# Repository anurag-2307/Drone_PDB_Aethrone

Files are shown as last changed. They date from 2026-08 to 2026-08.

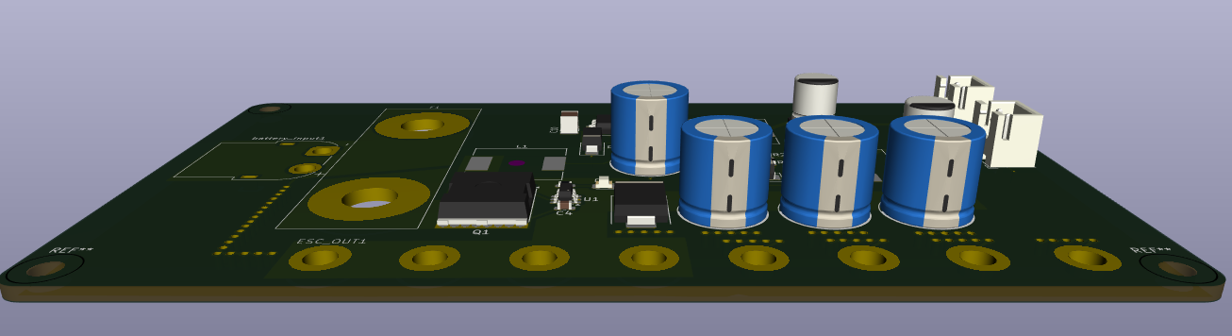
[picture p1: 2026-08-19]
images/3D_x_axis_view.png

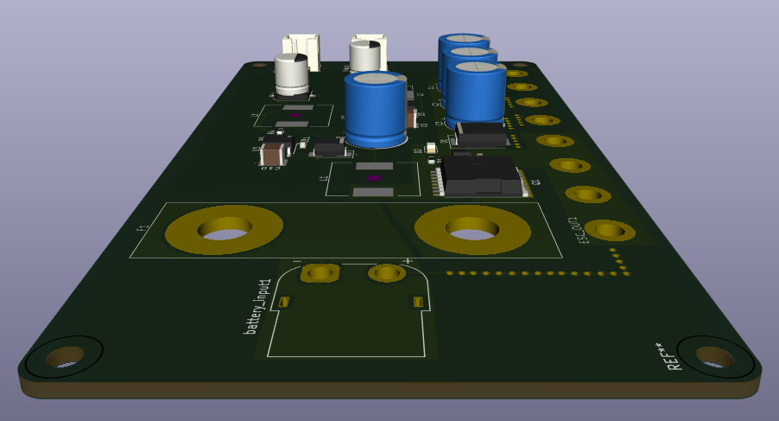
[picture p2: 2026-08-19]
images/3D_z_axis_view.png

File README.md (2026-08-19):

# Drone_PDB_Aethrone

---

Candidate : Anurag Patankar

Personal Email : patankaranurag23@gmail.com

---

### Problem Statement :
Drone Power Distribution Board (PDB)

---
### Objective : 
Design a Power Distribution Board (PDB) for a medium-sized multirotor UAV capable of safely distributing power from a 6S LiPo battery to the avionics and propulsion systems.

## System Specifications

Input source - 6S LiPo battery, 18 V – 25.2 V (3.0–4.2 V/cell)
Continuous current - 80 A
Peak current - 120 A
Regulated outputs -	5 V @ 3 A, 12 V @ 2 A
Unregulated output  -	Battery voltage direct to ESC1–ESC4
PCB	2-layer, 3 oz copper (both outer layers)
Target thermal design margin - 20 °C rise above ambient
Input Connectors - XT60 (6S LiPo datasheet suggests XT90 for 80A continuous current, but the problem statement mentioned this, so I have used XT60 instead)
Output Connectors (Non-ESC) - JST
Output Connectors (ESC) - Solder holes

Note: Copper sizing is assumed to be at 3oz as it was not mentioned which size is to be used in the problem statement.

---

### Input Protection

1. Reverse Polarity Protection — U1 (LM74700) + Q1 (IPT015N10N5)

Rather than a series diode (which would waste power as heat at 80 A) , meaning 24–40 W burned continuously), the board uses an ideal diode controller driving an N-channel MOSFET, which behaves like a near-lossless diode.

U1 – TI LM74700-Q1: an ideal-diode controller rated for a 3.2 V–65 V supply range, covering the 18–25.2 V input. It drives an external NMOS and regulates its forward voltage drop to ~20 mV, versus the 300–500 mV of a real diode. It also blocks reverse current if the battery is momentarily disconnected/reconnected backward or during a fault, and responds in under 1 µs.
Q1 – Infineon IPT015N10N5: a 100 V, 300 A-rated N-channel MOSFET with a maximum Rds(on) of 1.5 mΩ. At 80 A continuous, conduction loss is I²R = 80² × 0.0015 ≈ 9.6 W; at 120 A peak, ≈21.6 W. The 300 A / 100 V rating gives sufficient margin over the operating envelope of 80 A/25.2 V. This MOSFET choice is what makes a lossless reverse polarity protection stage feasible at this current level, since a lower-current MOSFET would need paralleling.

---
2. TVS Diode

A unidirectional TVS Diode is placed across the protected rail to protect against voltage spikes. When the MOSFET turns off, it will create high voltage spikes (V = L. di/dt). To suppress this,  we use a bulk capacitor(s). E = $\frac{1}{2} \cdot L \cdot I$ and since the energy needs to be stored in the capacitor as well, $E = \frac{1}{2} \cdot C \cdot (V_{max}^2 - V_{nominal}^2)$. After some calculations, we get about C = 1666uF. To minimize the ESR, we place these in parallel instead of 1 big capacitor. Hence 680u * 3 = 2040uF.  

---
3. Fuse

Since we have to handle 120A (peak), the fuse needs to be a MIDI/MEGA style fuse. Since KiCAD doesn't have these footprints readily available, I created it myself with through-holes so that it can be soldered later on.

---
4. TPS5430, TPS5420 buck converters

We needed 5V@3A and 12V@2A, thus these buck converters were chosen after going through the datasheet. TPS5430 can provide a constant current of about 3A, while the TPS5420 can provide a constant current of 2A. 

Feedback Resistors calculation (TPS5430):
Vout = Vref × (1 + R2/R3)
5 V = 1.221 V × (1 + 10 kΩ / R3)
R3 = 10 kΩ / (5/1.221 − 1) ≈ 3.24 kΩ

(TPS5420):
12 V = 1.221 V × (1 + 10 kΩ / R5)
R5 = 10 kΩ / (12/1.221 − 1) ≈ 1.13 kΩ

---
5. Trace Width Calculation:

120 A peak (peak) at 3 oz for	20 °C rise (assuming) is about ~7917 mil²	≈ 48.6 mm which is massive. That is why I have used copper pour instead to dissipate heat evenly.
3A constant at 5V => 1 mm width. This is deliberately kept higher to reduce IR drop, and it also keeps output regulation tighter under load. 
2A constant at 12V => 1 mm width. Same reasoning as above. 

The standard used to calculate the trace widths is **IPC-2221**.

---
6. Via sizing
Via sizing basis: 0.8 mm drill / 1.2 mm pad, ≈4.8 A per via at 20 °C rise (1 oz barrel plating assumed). Thus for each ESC output, TVS diode GND, Bulk capacitor GND, 5 vias are placed and about 20 for Battery input ground pin. Default via sizes are used for all other components.

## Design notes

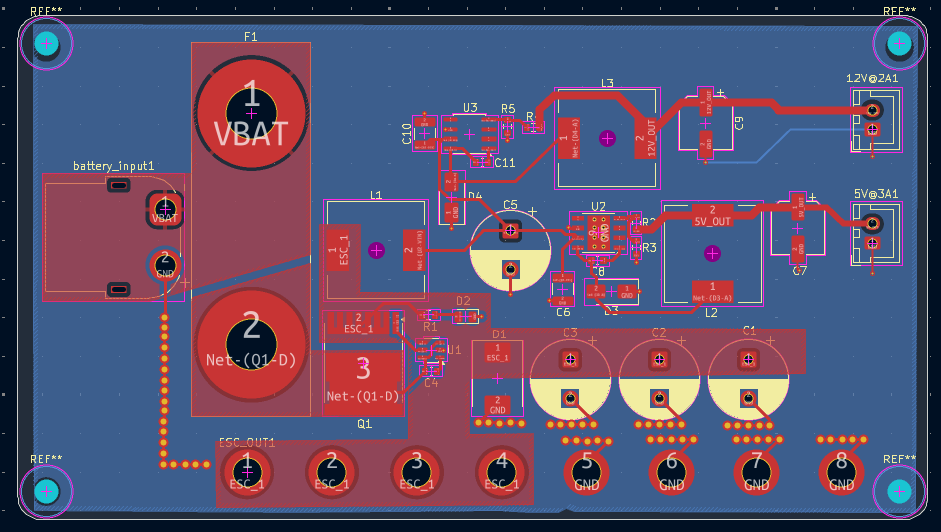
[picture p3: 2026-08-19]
images/Layout_view.png

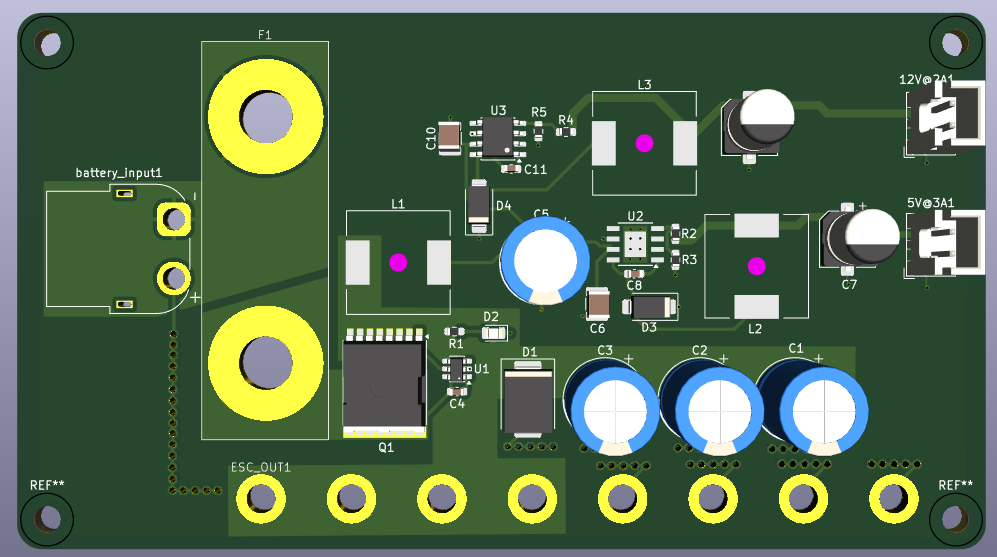
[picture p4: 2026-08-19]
images/3D_top_view.png

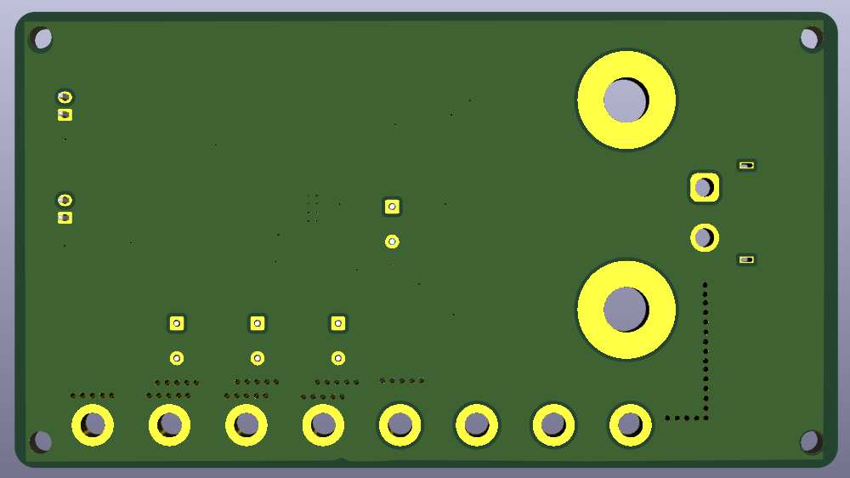
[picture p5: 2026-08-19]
images/3D_bottom_view.png

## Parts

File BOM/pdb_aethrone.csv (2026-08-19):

Reference | Qty | Value | DNP | Exclude from BOM | Exclude from Board | Exclude from Simulation | Exclude from Position Files | Footprint | Datasheet
5V@3A1,12V@2A1 | 2 | Conn_01x02_Pin |  |  |  |  | ${EXCLUDE_FROM_POS_FILES} | Connector_JST:JST_XH_B2B-XH-A_1x02_P2.50mm_Vertical
battery_input1 | 1 | Conn_01x02_Pin |  |  |  |  | ${EXCLUDE_FROM_POS_FILES} | Connector_AMASS:AMASS_XT60PW-F_1x02_P7.20mm_Horizontal
C1,C2,C3,C5 | 4 | 680u |  |  |  |  | ${EXCLUDE_FROM_POS_FILES} | Capacitor_THT:CP_Radial_D10.0mm_P5.00mm
C4 | 1 | 100n |  |  |  |  | ${EXCLUDE_FROM_POS_FILES} | Capacitor_SMD:C_0603_1608Metric
C6,C10 | 2 | 10u |  |  |  |  | ${EXCLUDE_FROM_POS_FILES} | Capacitor_SMD:C_1210_3225Metric
C7 | 1 | 220u |  |  |  |  | ${EXCLUDE_FROM_POS_FILES} | Capacitor_SMD:CP_Elec_6.3x7.7
C8,C11 | 2 | 10n |  |  |  |  | ${EXCLUDE_FROM_POS_FILES} | Capacitor_SMD:C_0603_1608Metric
C9 | 1 | 100u |  |  |  |  | ${EXCLUDE_FROM_POS_FILES} | Capacitor_SMD:CP_Elec_6.3x7.7
D1 | 1 | TVS_D |  |  |  |  | ${EXCLUDE_FROM_POS_FILES} | Diode_SMD:D_SMC
D2 | 1 | LED |  |  |  |  | ${EXCLUDE_FROM_POS_FILES} | LED_SMD:LED_0805_2012Metric
D3,D4 | 2 | B340 |  |  |  |  | ${EXCLUDE_FROM_POS_FILES} | Diode_SMD:D_SMA | http://www.jameco.com/Jameco/Products/ProdDS/1538777.pdf
ESC_OUT1 | 1 | Conn_01x08_Pin |  |  |  |  | ${EXCLUDE_FROM_POS_FILES} | Library_fuse:ESC_Pins
F1 | 1 | Fuse |  |  |  |  | ${EXCLUDE_FROM_POS_FILES} | Library_fuse:Untitled
L1 | 1 | 22u |  |  |  |  | ${EXCLUDE_FROM_POS_FILES} | Inductor_SMD:L_12x12mm_H6mm
L2 | 1 | 15u |  |  |  |  | ${EXCLUDE_FROM_POS_FILES} | Inductor_SMD:L_12x12mm_H6mm
L3 | 1 | 33u |  |  |  |  | ${EXCLUDE_FROM_POS_FILES} | Inductor_SMD:L_12x12mm_H6mm
Q1 | 1 | IPT015N10N5 |  |  |  |  | ${EXCLUDE_FROM_POS_FILES} | Package_TO_SOT_SMD:Infineon_PG-HSOF-8-1 | http://www.infineon.com/dgdl/Infineon-IPT015N10N5-DS-v02_01-EN.pdf?fileId=5546d4624a75e5f1014ac94680661aff
R1,R2,R4 | 3 | 10k |  |  |  |  | ${EXCLUDE_FROM_POS_FILES} | Resistor_SMD:R_0603_1608Metric
R3 | 1 | 3.24k |  |  |  |  | ${EXCLUDE_FROM_POS_FILES} | Resistor_SMD:R_0603_1608Metric
R5 | 1 | 1.13k |  |  |  |  | ${EXCLUDE_FROM_POS_FILES} | Resistor_SMD:R_0603_1608Metric
U1 | 1 | LM74700 |  |  |  |  | ${EXCLUDE_FROM_POS_FILES} | Package_TO_SOT_SMD:SOT-23-6 | http://www.ti.com/lit/gpn/LM74700-Q1
U2 | 1 | TPS5430DDA |  |  |  |  | ${EXCLUDE_FROM_POS_FILES} | Package_SO:TI_SO-PowerPAD-8_ThermalVias | http://www.ti.com/lit/ds/symlink/tps5430.pdf
U3 | 1 | TPS5420D |  |  |  |  | ${EXCLUDE_FROM_POS_FILES} | Package_SO:SOIC-8_3.9x4.9mm_P1.27mm | http://www.ti.com/lit/ds/symlink/tps5420.pdf

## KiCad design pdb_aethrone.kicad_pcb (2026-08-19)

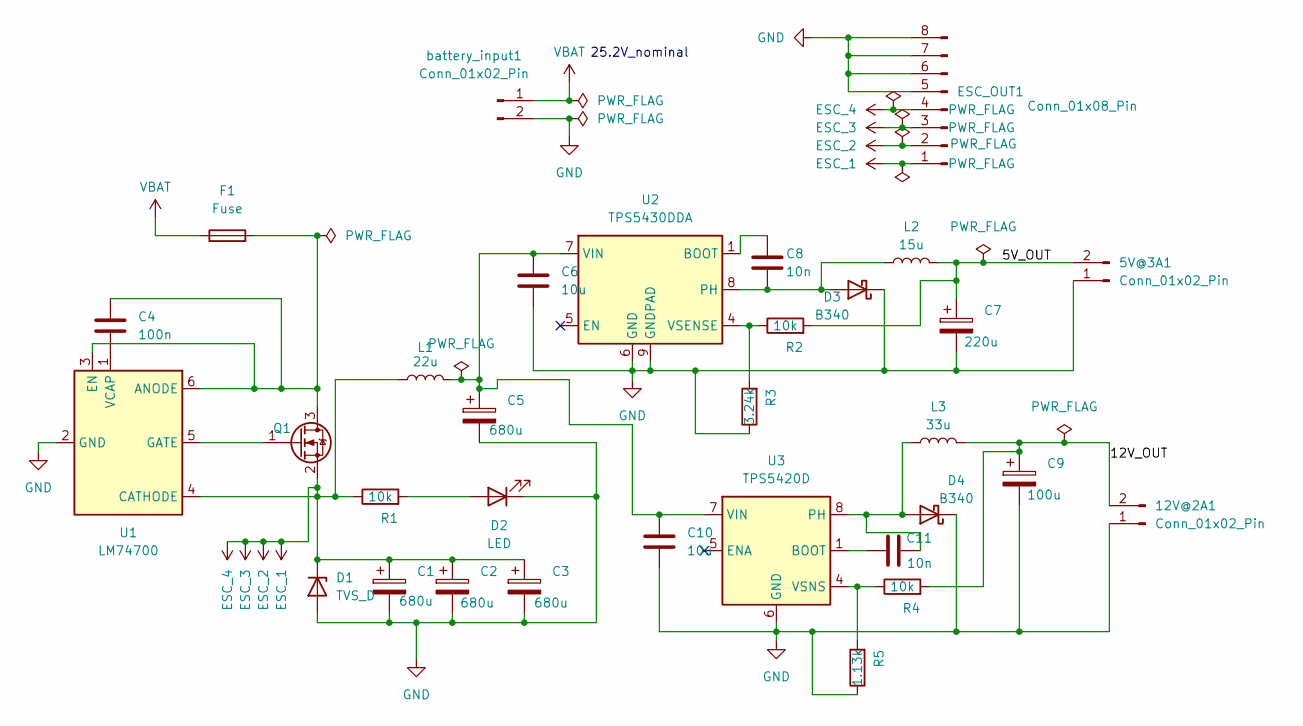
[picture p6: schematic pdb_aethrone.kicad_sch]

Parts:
5V@3A1, 12V@2A1: Conn_01x02_Pin; JST_XH_B2B-XH-A_1x02_P2.50mm_Vertical
C1, C2, C3, C5: 680u; CP_Radial_D10.0mm_P5.00mm
C4: 100n; C_0603_1608Metric
C6, C10: 10u; C_1210_3225Metric
C7: 220u; CP_Elec_6.3x7.7
C8, C11: 10n; C_0603_1608Metric
C9: 100u; CP_Elec_6.3x7.7
D1: TVS_D; D_SMC
D2: LED; LED_0805_2012Metric
D3, D4: B340; D_SMA
ESC_OUT1: Conn_01x08_Pin; ESC_Pins
F1: Fuse; Untitled
L1: 22u; L_12x12mm_H6mm
L2: 15u; L_12x12mm_H6mm
L3: 33u; L_12x12mm_H6mm
Q1: IPT015N10N5; Infineon_PG-HSOF-8-1
R1, R2, R4: 10k; R_0603_1608Metric
R3: 3.24k; R_0603_1608Metric
R5: 1.13k; R_0603_1608Metric
U1: LM74700; SOT-23-6
U2: TPS5430DDA; TI_SO-PowerPAD-8_ThermalVias
U3: TPS5420D; SOIC-8_3.9x4.9mm_P1.27mm
battery_input1: Conn_01x02_Pin; AMASS_XT60PW-F_1x02_P7.20mm_Horizontal

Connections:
/5V_OUT: 5V@3A1.2, C7.1, L2.2, R2.2
/12V_OUT: 12V@2A1.2, C9.1, L3.2, R4.2
ESC_1: C1.1, C2.1, C3.1, D1.1 (K), ESC_OUT1.1, ESC_OUT1.2, ESC_OUT1.3, ESC_OUT1.4, L1.1, Q1.2 (S), R1.1, U1.4 (CATHODE)
GND: 5V@3A1.1, 12V@2A1.1, C1.2, C2.2, C3.2, C5.2, C6.2, C7.2, C9.2, C10.2, D1.2 (A), D2.1 (K), D3.1 (K), D4.1 (K), ESC_OUT1.5, ESC_OUT1.6, ESC_OUT1.7, ESC_OUT1.8, R3.1, R5.1, U1.2 (GND), U2.6 (GND), U2.9 (GNDPAD), U3.6 (GND), battery_input1.2
unnamed: D2.2 (A), R1.2
unnamed: C8.2, D3.2 (A), L2.1, U2.8 (PH)
unnamed: C11.2, D4.2 (A), L3.1, U3.8 (PH)
unnamed: C4.1, F1.2, Q1.3 (D), U1.3 (EN), U1.6 (ANODE)
unnamed: Q1.1 (G), U1.5 (GATE)
unnamed: C4.2, U1.1 (VCAP)
unnamed: C8.1, U2.1 (BOOT)
unnamed: C5.1, C6.1, C10.1, L1.2, U2.7 (VIN), U3.7 (VIN)
unnamed: R2.1, R3.2, U2.4 (VSENSE)
unnamed: C11.1, U3.1 (BOOT)
unnamed: R4.1, R5.2, U3.4 (VSNS)
VBAT: F1.1, battery_input1.1

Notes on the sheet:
25.2V_nominal

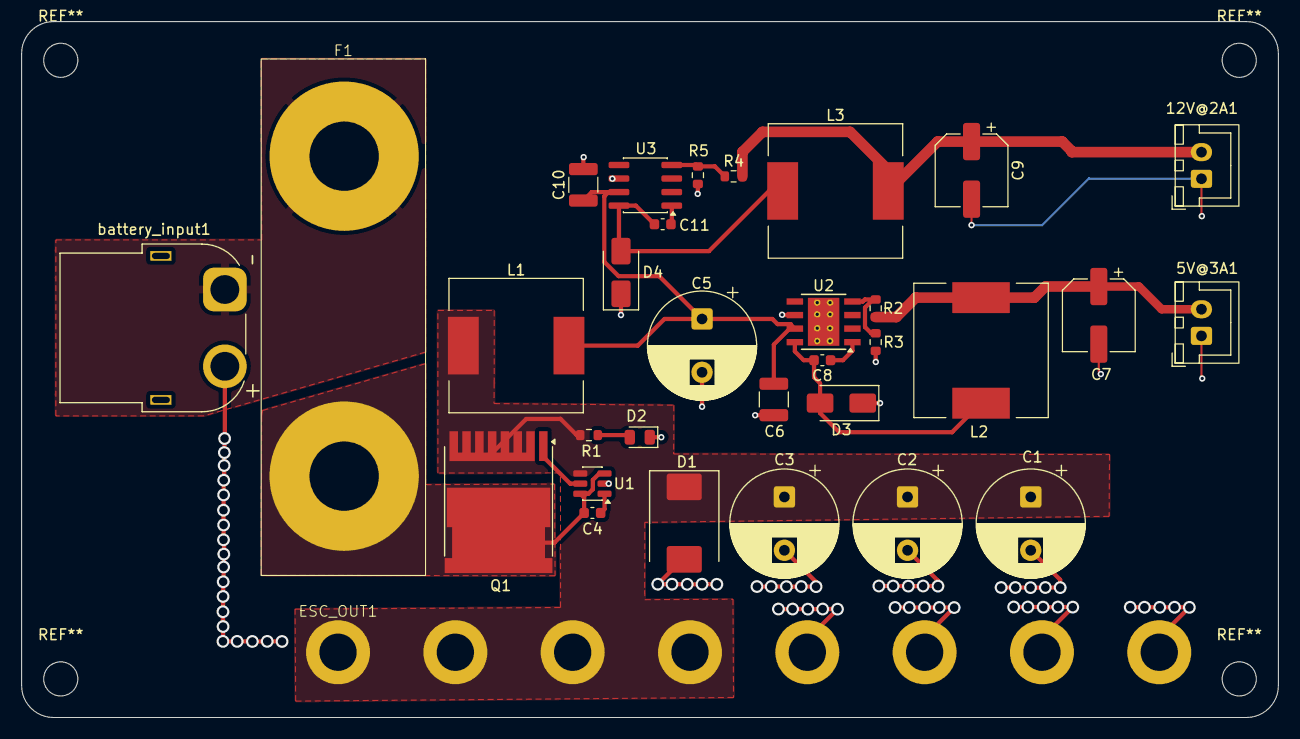
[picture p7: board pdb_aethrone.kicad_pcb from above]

Board: 2 copper layers, 117.8 x 65.2 mm, 32 parts (0 on the bottom side), 16 nets.
